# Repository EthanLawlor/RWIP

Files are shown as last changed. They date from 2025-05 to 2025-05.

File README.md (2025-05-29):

# 🛰️ Reaction Wheel Inverted Pendulum

This repository contains all hardware and software resources for the **Reaction Wheel Inverted Pendulum** project — a physical model of a CubeSat's attitude correction and control system. Developed as part of a Bachelor of Engineering (Honours) in Mechatronics at TU Dublin, the system demonstrates closed-loop stabilization using reaction wheels, an IMU, and PID-based control.

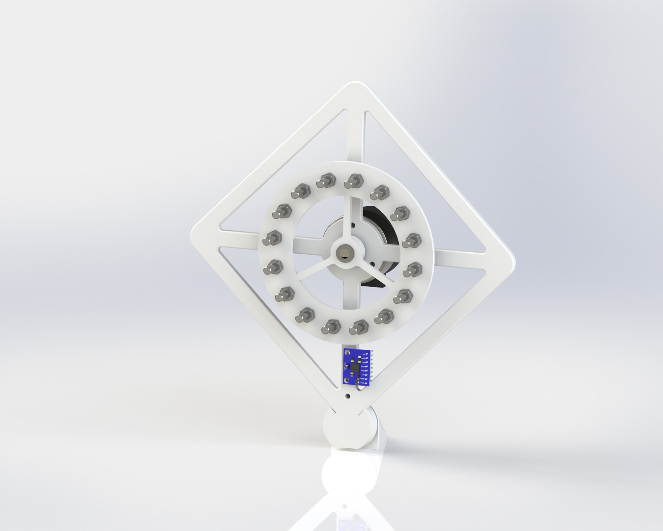
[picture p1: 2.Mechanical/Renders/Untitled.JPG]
3D Render of RWIP
  
*Figure: 3D render of the Reaction Wheel Inverted Pendulum prototype*

---

## 📦 Repository Structure

0. **Documentation**  
   - `RWIP-ProjectReport.pdf` – Full project report with modelling, design, and results

1. **Electrical**  
   - `KiCAD-PCB/` – Custom PCB for ATmega328P-based MCU, IMU, and power electronics  
   - Includes schematics, PCB layout, and Gerber files

2. **Mechanical**  
   - `SolidWorks-Assembly/` – Full CAD model of the pendulum frame and flywheel  
   - `STL-Files/` – 3D-printable parts for prototyping the mechanical structure

3. **Software**  
   - `Firmware/` – Microcontroller code for ATmega328P (Arduino-compatible)  
   - Implements sensor fusion (complementary & Kalman filters), cascade PID control, and encoder-based velocity feedback

---

## 🧠 Project Overview

This project simulates and physically demonstrates a 1U CubeSat’s ability to stabilize itself using internal momentum exchange via a reaction wheel. The system uses:

- **IMU**: MPU6050 (accelerometer + gyroscope)
- **Motor**: Nidec 24H brushless DC motor with encoder
- **MCU**: ATmega328P (Arduino Uno or custom PCB)
- **Control System**: Cascaded PID controller with feedback from IMU and encoder

---

## 🔬 Key Features

- Real-time stabilization of a pendulum system using reaction wheels
- Sensor fusion for clean angular state estimation (Kalman & complementary filters)
- Encoder RPM feedback and motor driver interface
- Fully 3D-printed mechanical structure with adjustable flywheel inertia
- Simulation-backed control strategy using Lagrangian modelling and Simulink validation

---

## 🛠️ Hardware Requirements

- ATmega328P MCU (Arduino Uno or custom PCB)
- MPU6050 IMU
- Nidec 24H brushless motor with integrated encoder
- 12V power supply and 5V linear regulator (LM7805)
- Reaction wheel (3D printed) with modular mass placement
- Supporting frame, bearings, and wiring

---

## 🧩 Software Features

- **Sensor integration**: I²C communication with MPU6050
- **State estimation**: Complementary and Kalman filtering
- **Control logic**: Cascaded PID loop with independent tuning
- **Motor interface**: PWM, direction, and brake pin management
- **Encoder**: Speed and direction estimation via interrupts
- **Serial monitoring**: Real-time feedback and tuning via PC interface

---

## 📚 Documentation

📄 The full design process, test results, simulations, and implementation details are documented in the [Project Report (PDF)](./0.Documentation/RWIP-ProjectReport.pdf).

---

## 🚀 Getting Started

### Setup Steps

1. **Assemble mechanical parts** using STL files or the full SolidWorks model
2. **Build the PCB** or use an Arduino Uno with the schematic provided
3. **Upload firmware** from `/Firmware` using Arduino IDE
4. **Power the system** with regulated 12V/5V supply
5. **View system behavior** and tune via Serial Plotter or Monitor

---

## 🔧 Control Strategy

- Inner loop: motor velocity PID control based on encoder feedback
- Outer loop: angle stabilization PID using fused IMU angle
- Designed and tuned iteratively based on test results and Simulink simulations

---

## 🧪 Future Work

- Expand to 3-axis stabilization using multiple wheels
- Switch to space-ready components for orbital deployment
- Integrate solar power system with MPPT for autonomous CubeSat operation
- Implement advanced control (LQR, SMC, nonlinear backstepping)

---

## 📝 License

This project is open-source and distributed under the terms of the [GNU General Public License v3.0 (GPL-3.0)](./LICENSE).

---

## 👤 Author

**Ethan Lawlor**  
B.Eng. Mechatronics  
Technological University Dublin

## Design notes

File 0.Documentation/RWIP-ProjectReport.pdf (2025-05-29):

TU DUBLIN BLANCHARDSTOWN

SCHOOL OF INFORMATICS AND ENGINEERING

# DEVELOPMENT OF AN OPTIMIZED ATTITUDE CORRECTION & CONTROL SYSTEM FOR A 1U CUBESAT

by

## Ethan Lawlor

## A report submitted in partial fulfilment of the

## requirements for the degree

### BACHELOR OF ENGINEERING (HONOURS) IN MECHATRONICS

### SUPERVISOR: SUBMISSION DATE:

ETHAN LAWLOR | BACHELOR OF ENGINEERING (HONOURS) IN MECHATRONICS | 30/04/2025
- ii -

### ABSTRACT

This report presents the end-to-end development of a reaction-wheel attitude-

determination-and-control system for a one-unit CubeSat. The work addresses the dual

challenge faced by small spacecraft, rapid detumbling after deployment and precise

pointing during routine operations, using only low-cost, commercial-off-the-shelf

hardware and firmware written from first principles .

A dynamic model of the inverted-pendulum system is derived with Lagrangian mechanics

and verified in simulation to guide controller design . Real-time attitude estimates fuse

accelerometer and gyroscope data first with a complementary filter and later with a Kalman

filter to reduce noise and drift while remaining computationally light . Stability is achieved

with a cascaded PID architecture in which an inner wheel-velocity loop feeds an outer

attitude loop, a structure selected for its ability to balance fast actuator dynamics against

slower body motions .

The report documents the electrical and mechanical builds, software flow charts, and

laboratory test methodology, detailing how iterative tuning, on-board data logging, sensor

filtering and a watchdog routine were used to refine performance and prevent controller

saturation . All design drawings and software codes are contained in the appendices to

lower the entry barrier for future attitude correction projects.

- iii -

### ACKNOWLEDGEMENTS

I would like to thank my lecturer, Niall Bell, for his guidance and support throughout this

project. His expertise and feedback were invaluable in shaping my work.

I also appreciate the encouragement and support from my friends and family, whose belief

in me kept me motivated during challenging moments.

Lastly, thank you to everyone who contributed to my education. Your help made this

journey possible.

- iv -

### DECLARATION

The work submitted in this report is the results of the candidate’s own investigations and

has not been submitted for any other award. Where use has been made of the work of other

people it has been fully acknowledged and referenced.

Ethan Lawlor

- v -

### TABLE OF CONTENTS

- vi -

- vii -

- viii -

### LIST OF ABBREVIATIONS

1 U One-Unit CubeSat standard (10 × 10 × 10 cm)

ADCS Attitude Determination and Control System

ADS Attitude Determination System

COTS Commercial Off-The-Shelf

DC | Direct Current (brushless DC motor)
DOF | Degrees Of Freedom (e.g., 6-DOF sensor)
EEPROM | Electrically Erasable Programmable Read-Only Memory
EPS | Electrical Power System
GNC | Guidance, Navigation and Control
GPS | Global Positioning System
GUI | Graphical User Interface
IMU | Inertial Measurement Unit
I²C / I2C | Inter-Integrated Circuit serial bus
ISS | International Space Station
LQR | Linear-Quadratic Regulator

MCU Microcontroller Unit (used for on-board processing)

MPPT Maximum Power Point Tracking (solar-array control)

PCB | Printed Circuit Board
PID | Proportional-Integral-Derivative (controller)
PPR | Pulses Per Revolution (encoder spec)

- ix -

PWM Pulse-Width Modulation

RPM | Revolutions Per Minute
RPS | Revolutions Per Second
RWS | Reaction Wheel System

RWIP Reaction Wheel Inverted Pendulum

SMC | Sliding Mode Control
USB | Universal Serial Bus

- x -

### LIST OF FIGURES

Figure 1. NanoRacks CubeSats being launched from the NanoRacks CubeSat Deployer on the ISS

- xi -

- xii -

### LIST OF TABLES

- 1 -

### Chapter 1 Introduction

This chapter presents a brief introduction to the need for attitude control in satellites, the

relevant background information and the scope of this project’s design solution.

Figure 1. NanoRacks CubeSats being launched from the NanoRacks CubeSat Deployer on

the ISS on February 25, 2014 (NASA Science Editorial Team, 2019).

### 1.1 An Introduction to CubeSats

A CubeSat is a class of small satellite designed to be deployed into orbit as secondary

payloads on a launch vehicle, or from the International Space Station, as seen in figure 1.

CubeSats are designed with a standardized size of 10x10x10 cm, also known as a “1U”

unit, to simplify their integration into deployment vehicles, but are modular and can consist

of multiple units, as seen in figure 2, and are often manufactured with commercial off-the-

shelf (COTS) components.

First conceived in 1999 to be a platform for scientific research and developing new space

technologies (NASA, 2024), as of 2024 there are now 2396 CubeSats launched, including

16 interplanetary missions. Academia was responsible for most CubeSat launches initially,

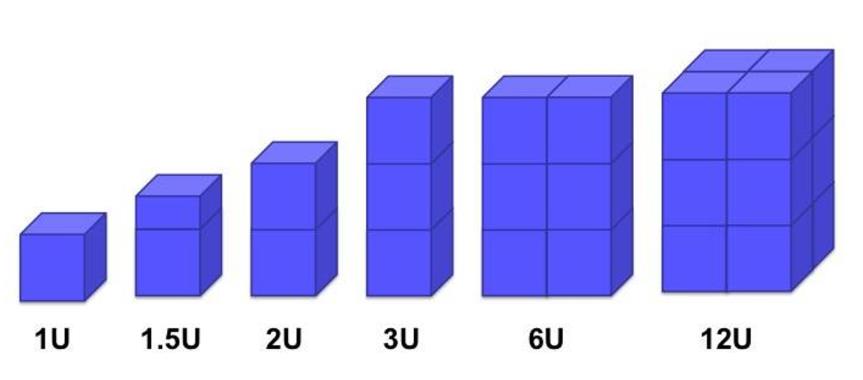
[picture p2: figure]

- 2 -

but by 2014 the majority of newly deployed CubeSats were for commercial or amateur

projects (Kulu, 2024).

Figure 2. A Sample of CubeSat Arrangements (NASA Science Editorial Team, 2019).

Most CubeSats deployed today are used for Earth observation, communications, and

scientific research, including climate monitoring, remote sensing, and technology testing.

Additionally, they are increasingly employed for commercial purposes, such as providing

data for telecommunication and internet services.

The expediated rate of growth in the nanosatellite commercial sector invites the need for

continuous development of increasingly simplified and COTS platforms for integration

into CubeSats.

### 1.2 Problem

Like larger satellites, CubeSats often feature multiple subsystems handling different tasks

in parallel including the flight computer, electrical power system (EPS), payload operation,

and primary control systems. A satellite’s Guidance, Navigation and Control (GNC)

subsystem encompasses the components used for position determination and the

components used by the Attitude Determination and Control Systems (ADCS) and is

crucial for a successful mission (NASA, 2024). Components used for ADCS include

- 3 -

reaction wheels, magnetorquers, thrusters, star trackers, sun sensors, Earth sensors, angular

rate sensors, and GPS receivers and antennas.

Due to asymmetric deployment forces and bumping with other CubeSats, tumbling

typically occurs during deployment. Some CubeSats operate normally while in a spin, but

others that require precise heading must be detumbled. Reaction wheels are commonly

used for their ability to impart relatively large amounts of moments on the overall system.

Once detumbled a CubeSats orientation may still needed to be controlled to align its

sensors for data acquisition or to optimize solar gain through its solar panel array. These

operations present the need to develop a control system for precise attitude control in three

axes for CubeSats, that doesn’t rely on exerting a force on an object external to the satellite.

### 1.3 Background

Figure 3. A Reaction Wheel being used to Control Orientation in one Axis (Dominik

Zaborniak, 2024).

The use of reaction wheels to control the orientation of a system is well-documented in

projects addressing the inverted pendulum problem, as illustrated in Figure 3 (Dominik

Zaborniak, 2024). In this case, the torque generated by the reaction wheel is sufficient to

counteract external disturbances and adjust the angular momentum of the system, including

the combined effects of the system's moment of inertia, existing angular momentums and

external disturbances. The reaction wheel imparts torque to the system, which is critical

for maintaining stability in an otherwise unstable configuration. An optimized control

- 4 -

system would regulate the torque applied by the reaction wheel based on the magnitude

and direction of the system's overall angular momentum, effectively stabilizing the system

and keeping it in an upright position.

To control the orientation of the CubeSat in three axes, three reaction wheels can be

arranged along its orthogonal axis, as in figure 4. This arrangement aligns each wheel to

impart a moment on the system around a primary axis of rotation, either the x-, y-, or z-

axis.

Figure 4. Three Axis Inverted Pendulum forming a cube (Bobrow, et al., 2020).

The Cubli, developed by Mohanarajah Gajamohan & colleagues in 2012, is an excellent

example of this three-axis configuration. In Cubli, the system dynamics are modelled using

Kane’s equations, and orientation of the system is described using Euler angles, and brakes

are incorporated to generate large torques from collisions with the wheel. These exert such

a large force on the system that Cubli can “jump” from a face to an edge, then from

balancing on the edge can jump again up onto a vertex, “catching” itself there and

maintaining balance (Mohanarajah, et al., 2012).

Other iterations of Cubli use various means of describing the angular displacement and

modelling the system dynamics. Papers by Fabio Bobrow and colleagues documents the

- 5 -

use of complex numbers to describe the angular displacement of a single cube face in 2D

(Bobrow, et al., 2020), and, by extension, unit ultra-complex numbers (quaternions) to

describe the angular displacement of the cube in 3D (Bobrow, et al., 2020). Using

quaternions avoids encountering singularities found in Euler angle mechanics, singularities

occur when the algorithm cannot find a solution to the required movements. The

Lagrange’s equations are used in these papers to derive a set of equations that describe the

motion of the system.

Once an equation of motion is determined, a control strategy is necessary to reduce and

eliminate the angle of displacement in the three dimensions and maintain stable orientation.

An example of a control algorithm reducing the angular velocity of a system in 3

dimensions to zero, i.e. trying to keep it still, is shown in figure 5. Proportional-Integral-

Derivative (PID) control is one of the most used methods for correcting orientation errors.

It adjusts the control input based on the current error, accumulated past error, and the rate

of change of the error. This method is effective for systems with relatively linear dynamics

and ensures precise orientation adjustments.

Another useful strategy is the Linear Quadratic Regulator (LQR), which minimizes a cost

function that penalizes both deviations from the desired state and the control effort. This is

particularly suitable when the system can be linearized around an equilibrium point,

providing optimal control for CubeSat attitude control around a point, while minimizing

both the angle state error and revolutions per minute (RPM) of the reaction wheel, keeping

the wheel speed to a minimum (Mohanarajah, et al., 2013).

- 6 -

Figure 5. An Example of PID control settling the angular velocity of a system

(Mohanarajah, et al., 2013)

These control strategies, when implemented appropriately, ensure that CubeSats maintain

precise orientation and stability in space.

### 1.4 Scope and Objectives

The scope of this project focuses on the design and development of an optimized attitude

correction and control system for a 1U CubeSat. The primary objective is to create a model

capable of stabilizing and orienting itself using reaction wheels as the primary actuators.

The model will simulate a CubeSat's behaviour, maintaining its orientation against external

factors such as gravitational forces, sensor noise, and the varying centre of mass and thus

the varying of moments of inertia configurations, not unlike when a CubeSat would deploy

a solar array. The project aims to ensure that the CubeSat remains stable, and can be

orientated about its yaw axis, enabling precise heading for data collection, optimal solar

panel alignment, and communication tasks.

Key technical objectives include conducting an in-depth literature review to investigate

current CubeSat attitude control technologies, reviewing flywheel system dynamics, and

analysing existing studies on control design for orientation. The project will then move on

- 7 -

to the design phase, including both mechanical and electronic components, with detailed

engineering drawings and circuit schematics. A comprehensive software flow diagram

outlining the control algorithms will also be developed.

Following the design, the project will simulate the proposed system using relevant software

tools to validate its functionality. Once validated, a prototype will be built, first for one

dimension then moving onto three dimensions, to verify the measurements and movements

of the attitude control system. The prototypes will be rigorously tested, and iterative

adjustments will be made to optimize the control algorithms based on performance

feedback. The final phase will involve comprehensive testing and evaluation to ensure the

CubeSat's attitude control system can stabilize the satellite and orient it to the desired

direction autonomously.

In addition to the core objectives, the project will explore the integration of a solar array

with Maximum Power Point Tracking (MPPT) to simulate varying configurations of mass

of the satellite. A graphical user interface (GUI) to display heading, pitch, roll, and a live

camera feed is also considered as a potential bonus feature to simulate data capture.

By the end of this project, a robust, low-cost, and efficient attitude control system for

CubeSats will be developed, with applications extending to public, private and commercial

sectors.

### 1.5 Document Overview

This document outlines the design, modelling, and testing of an optimized attitude

correction and control system for a 1U CubeSat. Chapter 1 introduces the key challenges

CubeSats face, particularly the need for precise attitude control to maintain proper

alignment of solar panels, sensors, and communication systems. The background section

discusses the use of reaction wheels for orientation control and explores various control

strategies that are employed to stabilize the CubeSat’s attitude in three dimensions.

Chapter 2 provides a comprehensive technical foundation for the CubeSat system. It begins

with the physical components of the CubeSat prototype, including the microcontroller,

- 8 -

motors, and reaction wheels. The chapter continues with a discussion on the derivation of

the equations of motion, which describe the CubeSat's dynamics and form the basis for the

attitude control system along with the PID error control. The different methods for

representing attitude, such as quaternions and Euler angles, highlighting their respective

advantages and challenges in CubeSat applications, are also detailed. This section explains

how these components are integrated to achieve stable and efficient attitude control.

In Chapter 3, the methodology for the construction of the CubeSat model is outlined,

followed by the implementation of the control system. This chapter also describes the

testing process, including simulations and real-world validation of the CubeSat's

performance. Chapter 4 presents the results from these tests, evaluating the effectiveness

of the attitude control system in stabilizing the model’s orientation. Finally, Chapter 5

concludes the report by summarizing the findings and offering recommendations for

further improvements in CubeSat attitude control systems.

- 9 -

### Chapter 2 Literature Review

This chapter presents a review of the technologies and methodologies for attitude control

in CubeSats. CubeSats require efficient and reliable systems to ensure precise attitude

control in orbit. This review covers essential topics, including the construction of a system

with manipulative dynamics, mathematical frameworks for attitude representation, and

linear and nonlinear control strategies. The work presented here is crucial to the

development of the CubeSat attitude correction system.

### 2.1 Reaction Wheel-Based Systems for Attitude Control

A reaction wheel system (RWS) is a key component in small spacecraft such as CubeSats

for precise attitude control, using spinning wheels to generate torques that modify the

spacecraft's orientation. As the wheels spin, they generate angular momentum, which is

transferred to the spacecraft due to the conservation of momentum. The principle can be

described by Newton’s Second Law of Motion when applied to rotating bodies, every

action having an equal but opposite reaction. This system does not require external

thrusters or fuel reservoirs, making it well-suited for small spacecraft like CubeSats, where

minimizing mass and maximizing efficiency are essential.

The Cubli is a prominent example of a 3D inverted pendulum system that uses three

reaction wheels mounted on the cube’s faces to control its orientation. By applying

controlled torques from these wheels, the Cubli can balance on its edge or corner. This

design, although originally developed for a ground-based balancing robot, provides the

relevant framework for CubeSat design due to the similarities in mechanics and constraints

on mass, volume, and power.

The mechanical structure of such RWS’s consists of a lightweight yet rigid housing, with

brushless DC motors driving the reaction wheels. For CubeSat applications, a similar

design can be adapted as the Cubli balancing in +1g gravity on Earth, proves the system’s

ability to work for space-specific, 0g, requirements.

- 10 -

In a CubeSat reaction wheel system, the reaction wheels are typically mounted on three

orthogonal axes. This setup provides full control over the spacecraft's attitude, allowing for

rotations around all three axes (yaw, pitch, and roll). The reaction wheels are controlled by

a feedback system that adjusts the wheel speeds based on input from sensors that measure

the spacecraft's orientation.

### 2.1.1 Mechanical Build of a Reaction Wheel Inverted Pendulum

For the development of a CubeSat model with a reaction wheel attitude control system, the

mechanical build would include:

1. Three Reaction Wheels: Each mounted on a face of the CubeSat. These wheels

will be coupled with motors to generate the required torques for attitude control.

2. Brushless DC Motors: These motors are ideal for CubeSats due to their efficiency,

precise control, and low power consumption. The motors must be mounted in such

a way that the CubeSat's centre of mass is close to the axis of rotation to minimize

the need for large control torques.

3. Structural Housing: The CubeSat housing must be designed to be lightweight and

durable, with a rigid framework that can withstand the forces generated by the

reaction wheels.

4. Sensors: IMUs (Inertial Measurement Units) are typically used for real-time

measurement of the CubeSat’s orientation. These units often combine

accelerometers, gyroscopes, and sometimes magnetometers to provide precise

attitude determination.

5. Microcontroller: A microcontroller unit (MCU) will be used to read the sensor

input and then output to the motor drivers accordingly based on the devised control

system. A development board with native Bluetooth and Wi-Fi connectivity will be

considered.

- 11 -
6. Electrical Power System: The electrical power system (EPS) will consist of a

battery bank with large enough capacity to support the three motors and other

electronics, a charge regulator for the battery and two voltage regulators, one for

the motors and one for the MCU and sensor

This mechanical setup allows for a compact and efficient attitude control system for

CubeSats, with minimal power consumption and no need for external propulsion systems.

The compact nature of CubeSats, however, imposes stringent limitations on mass and

power, requiring optimization of both the mechanical and electrical systems.

### 2.1.2 Reaction Wheel

The reaction wheel is a critical component in CubeSat attitude control systems, used to

generate torques that alter the spacecraft's orientation. The fundamental principle behind a

reaction wheel is the conservation of angular momentum: when the wheel spins, it creates

angular momentum, and any change in the wheel's angular velocity results in a

corresponding change in the CubeSat’s attitude. This key principle is essential for precisely

controlling the model’s orientation through the adjustment of the wheel’s speed and torque.

Figure 6. Inertia of an Annular Cylinder about Centre Axis (Moebs, et al., 2016)

The moment of inertia (I) of the reaction wheel is given by:

I =

m
2

(R1

2 + R2

2
) | (2.1)

- 12 -

Where m is the mass, and R1 and R2 are the inner and outer radii of the wheel. This

parameter determines the required torque to achieve specific angular accelerations

(Moebs, et al., 2016).

Key Parameters for Reaction Wheel Design:

### 1. Mass (m):

The mass of the reaction wheel affects its moment of inertia and torque generation.

A lighter wheel reduces the CubeSat's overall weight but may limit torque

generation, requiring a balance between sufficient torque and weight.

### 2. Radius (r):

The radius influences the moment of inertia. A larger radius increases torque

capability but also raises mass and power requirements.

### 3. Torque (τ):

The torque generated by the reaction wheel is related to angular acceleration by:

τ = I ⋅ α | (2.2)

Where α is angular acceleration. This equation governs how the reaction wheel’s

change in speed affects the model’s orientation (Beer & Johnston, 1989).

### 4. Angular Velocity (ω):

The angular velocity relates to angular momentum L, given by:

L = I ⋅ ω | (2.3)

Where ω is the angular velocity. This stored angular momentum is transferred to

the CubeSat, enabling attitude control (State Examinations Commission, 2011).

- 13 -

### 5. Kinetic Energy (Ek):

The kinetic energy in the reaction wheel is:

Ek =

1
2

### Iω²

(2.4)

This energy affects the CubeSat's power consumption and how efficiently it can

maintain orientation (State Examinations Commission, 2011).

### 6. Potential Energy (Ep):

The potential energy, especially in varying gravitational fields or when adjusting

orientation relative to a force, is given by:

Ep = mgℎ | (2.5)

Where h is the height or displacement relative to the gravitational source. This

energy must be accounted for in attitude adjustments (State Examinations

Commission, 2011).

### 7. Control Speed Limit:

The reaction wheel has physical limits, such as the maximum angular velocity and

the maximum torque it can generate. These limits must be factored into the control

system to avoid overdriving the wheel and ensure the CubeSat operates within its

capabilities.

### 8. Energy Efficiency:

Energy consumption is a key factor in CubeSat design. The reaction wheel's energy

use, including kinetic and potential energy, should be optimized to balance power

requirements for attitude adjustments within the CubeSat's limited power budget.

- 14 -

### 9. Rotational Inertia and Response Time:

The CubeSat's overall inertia determines how quickly it can change its orientation.

A higher CubeSat inertia requires more torque to achieve the same angular

acceleration, influencing the system's response time and stability (Mohanarajah, et

al., 2013).

By selecting appropriate values for these design parameters—such as mass, radius, moment

of inertia, torque, and angular velocity—the reaction wheel can be optimized for precise

CubeSat attitude control. These parameters are essential for ensuring the wheel can

generate the required torques while maintaining energy efficiency and operating within the

CubeSat's power constraints. Modelling these parameters accurately is key to integrating

the reaction wheel into the CubeSat’s attitude control system, ensuring stable and effective

orientation adjustments in space.

### 2.1.3 Motor

The reaction wheel system will use the Nidec24H brushless DC motor (model NCJ-24H-

12-01), which integrates the motor, motor driver, and encoder into a single unit. This

integrated design simplifies the CubeSat's attitude control system by reducing the number

of components and minimizing space, weight, and power consumption—critical

considerations for CubeSat applications. This model was chosen as it’s a readily available

COTS component.

- 15 -

Figure 7. Brushless DC Motor Nidec 24H (Nidec Corp., 2024)

Key Parameters for Motor Design:

### 1. Operating Voltage (V):

The motor operates at 12 V, which directly impacts the power consumption and

overall energy budget. This voltage level is chosen to balance power requirements

with the CubeSat’s limited energy supply.

### 2. Continuous Torque (τ):

The motor generates a continuous torque of 25 mN·m, which is essential for the

reaction wheel to produce the necessary forces for attitude control. This torque

value is a key parameter for determining the wheel's ability to alter the model’s

orientation.

### 3. Maximum Speed (ωmax):

The motor has a maximum speed of 2,500 RPM, which dictates how quickly the

CubeSat can adjust its orientation. The speed determines how fast the reaction

wheel can be spun to achieve desired attitude changes.

- 16 -

### 4. Encoder Resolution (PPR):

The motor includes an integrated dual line encoder with 200 pulses per revolution

(PPR), providing high-resolution feedback on the motor’s speed and position. This

allows feedback for precise control of the reaction wheel’s rotational velocity and

accurate feedback for attitude control.

### 5. Maximum Current (Imax):

The motor has a maximum current rating of 0.9 A, ensuring that it will not exceed

the model’s power supply capacity. This is important for managing the CubeSat’s

energy usage and ensuring that the motor operates within safe limits.

### 6. Efficiency and Design:

The brushless design of the motor ensures high efficiency, which is critical for long-

duration space missions where energy conservation is essential. The motor's design

also minimizes maintenance needs, as it has no brushes that could wear out over

time.

### 7. Control via PWM:

The motor speed is regulated by PWM (Pulse Width Modulation) control, which

adjusts the duty cycle of the signal sent to the motor driver. By varying the duty

cycle, the average voltage applied to the motor is controlled, which in turn controls

the speed and torque of the reaction wheel. This method efficiently regulates the

motor’s performance while minimizing power loss, allowing for fine control over

the reaction wheel’s speed.

These parameters are crucial for determining system power requirements and motor

behaviour, ensuring the reaction wheel system operates efficiently, while the integrated

encoder allows for precise feedback, enabling the model to maintain and accurately adjust

wheel speed (Nidec Corp., 2024).

- 17 -

### 2.1.4 Structure

The CubeSat structure is designed to support the reaction wheel and other critical components while

maintaining overall system integrity. It's built to house the motor, IMU, and other subsystems,

ensuring everything is secure and well-balanced.

Figure 8. Inertia for Slab About Centre Axis (Moebs, et al., 2016).

The main job of the structure is to provide a solid foundation for the reaction wheel and motor,

while also keeping the system’s centre of mass balanced. To get an accurate sense of the system's

dynamics in one dimension, the moment of inertia of the structure is calculated using a simple slab

model, as follows:

I =

m(a

2 + b

2
)
12

(2.6)

where m is the mass, and a and b are the dimensions of the model. This gives a starting point for

modelling the rotational behaviour of the CubeSat. As the CubeSat will be balancing on a vertex,

due to the limitations of gravity, the Parallel Axis Theorem is used to account for the offset of the

centre of rotation from the CubeSat’s centre of mass:

Ib = Ic + md

2
(2.7)

When dealing with three axis of rotation, the inertia tensor is a key parameter needed to model the

CubeSat's rotational dynamics. The inertia tensor, I, describes how the mass is distributed relative

to the CubeSat's three principal axes of rotation. For a simple CubeSat model, the inertia tensor can

be approximated using the parallel axis theorem, taking into account the mass distribution and the

geometry of the CubeSat. For a cube, the inertia tensor is diagonal and can be expressed as:

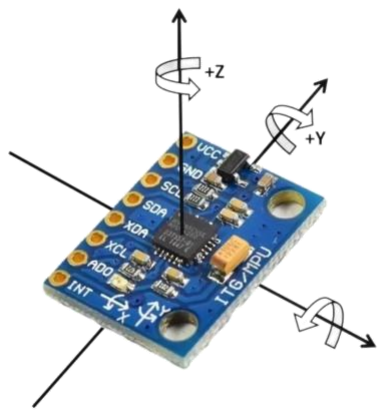
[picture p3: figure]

- 18 -

I =
[

1
6

mtotal(a

2 + b

2
) | 0 | 0

0

1
6
| mtotal(a

2 + b

2
) | 0
0 | 0

1
6
| | mtotal(a

2 + b

2
)
]

(2.8)

Where a, b, and c are the dimensions of the CubeSat, and mtotal is the total mass. The diagonal

elements represent the moments of inertia about the principal axes, while the off-diagonal elements

represent the products of inertia, which are assumed to be zero for a symmetric CubeSat with a

simple geometry (Beer & Johnston, 1989).

These parameters—total mass, centre of mass, and inertia tensor—are essential for deriving the

equations of motion for the CubeSat’s attitude control system. The equations of motion describe

the CubeSat's rotational dynamics under the influence of external torques (e.g., from the reaction

wheel) and disturbances (e.g., gravitational gradients, solar pressure). By accurately modelling

these parameters, the dynamics of the CubeSat can be simulated and controlled effectively using

the reaction wheel system.

### 2.1.5 Sensors

Figure 9. MPU6050 6 Axis Accelerometer/Gyroscope (Arrendondo, 2023)

The CubeSat model utilizes the MPU6050 sensor, an Inertial Measurement Unit (IMU)

that integrates both a 3-axis accelerometer and a 3-axis gyroscope. This sensor is essential

for determining the CubeSat's orientation and angular velocity in each axis, which are key

for the attitude control system. The MPU6050 provides real-time feedback on the

- 19 -

CubeSat's position and motion, enabling the precise measurements required to correctly

adjust the reaction wheel's torque in order to stabilize the model’s orientation.

The accelerometer measures linear acceleration along the X, Y, and Z axes, providing

information on the gravitational forces acting on the CubeSat. This data is used to

determine the CubeSat's tilt or attitude relative to the Earth’s surface. The gyroscope

measures the angular velocity along the same three axes, allowing the CubeSat's rotational

motion to be tracked and enabling the system to compensate for changes in orientation.

The MPU6050 communicates via I2C protocol, allowing for efficient data transmission

between the sensor and the CubeSat's microcontroller (ESP32). The sensor offers high

precision, with a range of ±2g to ±16g for the accelerometer and ±250 to ±2000 degrees

per second for the gyroscope, making it suitable for precise attitude measurement in small

spacecraft applications like CubeSats. (DFRobot, 2024)

This sensor is integral to the CubeSat’s attitude determination system (ADS), providing

the necessary data for the control algorithms to adjust the reaction wheel’s speed and thus,

its torque. By integrating the MPU6050 with the CubeSat's attitude control system, the

satellite can measure accurate orientation during its mission.

### 2.1.6 Microcontrollers

Microcontrollers serve as the central processing units in CubeSat systems, managing sensor data

processing, control algorithms, and communication tasks. The choice of microcontroller depends

on various factors such as processing power, memory capacity, power consumption, and interface

availability. Two commonly used microcontrollers are the Arduino Uno and the ESP32.

### 2.1.6.1 Arduino Uno

The Arduino Uno R3 development board, a widely used and easy-to-program microcontroller. It is

built around the ATmega328P 8-bit microcontroller, running at a clock speed of 16 MHz. Although

less powerful than other modern microcontrollers, it is capable of handling essential data processing

from the sensors and controlling the reaction wheel motor using PWM signals.

- 20 -

Figure 10. Arduino Uno Development Board

The Arduino Uno includes 14 digital input/output pins (of which 6 can provide PWM output), 6

analog inputs, and a USB connection for programming and serial communication. Its simplicity

and reliability make it a suitable choice for early-stage CubeSat designs and developmental

projects. The microcontroller offers 32KB of flash memory, 2KB of SRAM, and 1KB of EEPROM,

which are sufficient for basic control algorithms and sensor interfacing tasks.

The I2C interface on the Arduino Uno is used to communicate with the MPU6050 sensor, while

the GPIO pins are used to drive the motor interface, enabling precise control of the reaction wheel.

While the Arduino Uno consumes slightly more power relative to more advanced boards, it remains

an accessible and well-supported platform for prototyping CubeSat control systems (Arduino,

2025).

### 2.1.6.2 ESP32

The ESP32-DevKitC development board, a powerful and energy-efficient microcontroller.

It features a dual-core 32-bit processor running at up to 240 MHz, which is capable of

handling real-time sensor data processing from the MPU6050 and controlling the reaction

wheel motor via PWM signals.

- 21 -

Figure 11. ESP32 Development Board (DigiKey, 2024)

The ESP32-WROOM-DA chip used for this development board includes Wi-Fi and

Bluetooth connectivity, useful for testing and debugging, as well as communication with a

ground station during development. The microcontroller has 4MB of flash memory and

520KB of SRAM, providing enough resources to store control algorithms and handle data

processing tasks. (DigiKey, 2024)

The I2C interface on the ESP32 is used to communicate with the MPU6050 sensor, while

its GPIO pins interface with the motor driver, allowing precise control of the reaction

wheel. With low power consumption, the ESP32-WROOM is well-suited for CubeSat

applications, balancing performance and power efficiency within the CubeSat’s limited

resources.

### 2.1.7 Electrical Power System

The CubeSat's Electrical Power System (EPS) is designed to manage the power distribution

and charging of the batteries. The system was developed using KiCAD, a widely used

open-source electronic design automation (EDA) tool, to create a custom printed computer

board (PCB) that meets the specific power requirements of the CubeSat’s components.

- 22 -

Figure 12. Custom PCB for Electrical Power System

The PCB is designed to regulate power from the CubeSat's solar panels and distribute it to

critical components, including the microcontroller, sensors, and reaction wheel motor. The

system incorporates a charging circuit for the CubeSat’s battery, ensuring that the battery

remains charged during operation while preventing overcharging or deep discharge, which

could damage the battery. Voltage regulators on the custom PCB provide stable power to

different subsystems, such as the ESP32 microcontroller and the MPU6050 sensor,

ensuring that each component receives the appropriate voltage for safe operation.

The EPS also includes power monitoring capabilities, allowing the CubeSat to track battery

voltage and current draw to optimize energy usage and ensure that the system remains

within its power limits during the mission. By integrating all these power management

functions into a single custom PCB, the system minimizes size, weight, and complexity

while providing reliable power to the CubeSat’s attitude control system and other

subsystems.

- 23 -

### 2.2 Mathematical Methods for Attitude Representation

Precise modelling of spacecraft dynamics is a crucial aspect of attitude control. CubeSat

attitude determination relies on mathematical methods for representing rotations and

calculating the required torques to control the spacecraft's orientation. The following

mathematical methods are commonly used in spacecraft attitude determination and control:

### 2.2.1 Euler Angles

Euler angles provide a simple method for describing the orientation of a rigid body in three-

dimensional space. Using three rotational angles—yaw, pitch, and roll—Euler angles

define the orientation of the spacecraft relative to a reference coordinate system. The

rotations are typically performed about fixed axes, such as:

### R = Rz

### (φ)Ry

### (θ)Rx

(ψ) | (2.9)

where:

- φ is the yaw angle (rotation about the z-axis),
- θ is the pitch angle (rotation about the y-axis),
- ψ is the roll angle (rotation about the x-axis).

Although Euler angles are easy to understand and implement, they suffer from gimbal lock,

where two of the rotation axes become aligned, causing a loss of one degree of freedom.

This limitation makes Euler angles unsuitable for continuous and precise control over large

rotations.

### 2.2.2 Quaternions

Quaternions offer a more robust solution for representing rotations in three-dimensional

space. A quaternion consists of one scalar and three vector components:

q = q0 + q1i + q2j + q3k | (2.10)

- 24 -

where q0 is the scalar part and q1, q2, q3 are the vector components. Quaternions are

particularly advantageous in CubeSat systems because they do not suffer from singularities

and allow for smooth and continuous rotations.

The relationship between the quaternion and rotation matrix is given by:

R = [

1 − 2(q2

2 + q3

2
) 2(q1
q2 − q0

q3

) 2(q1
q3 + q0

q2

)
2(q1
q2 + q0

q3

) 1 − 2(q1

2 + q3

2
) 2(q2
q3 − q0

q1

)
2(q1
q3 − q0

q2

) 2(q2
q3 + q0

q1

) 1 − 2(q1

2 + q2

2
)

] (2.11)

This matrix can be used to transform vectors from the body frame to the inertial frame,

ensuring precise attitude control. (Kuipers, 1999)

### 2.2.3 Lagrangian Mechanics

Lagrangian mechanics provides a framework for modelling the dynamics of complex

systems, including spacecraft. The Lagrangian L is defined as the difference between the

kinetic energy T and potential energy U of the system:

L = T − U | (2.12)

The equations of motion are derived using the Euler-Lagrange equations, which describe

the dynamics of the system in terms of generalized coordinates (such as orientation angles)

and velocities:

d
dt (

dL

### dqi

̇

) −

dL

### dqi

= 0 | (2.13)

These equations allow the spacecraft's rotational behaviour to be predicted, providing the

necessary models for control system design (Goldstein, et al., 2002).

### 2.3 Sensor Integration for Attitude Determination

Inertial Measurement Units (IMUs) are essential for accurate attitude determination in

CubeSats, providing real-time data on orientation, angular velocity, and acceleration. A

typical IMU combines an accelerometer and a gyroscope to deliver comprehensive

- 25 -

orientation information. The MPU-6050 is a widely used IMU that integrates a 3-axis

accelerometer and a 3-axis gyroscope, offering reliable attitude data.

The accelerometer measures the force of gravity along each axis, enabling the

determination of tilt angles, while the gyroscope measures angular velocity, allowing for

the tracking of changes in orientation. To enhance the accuracy and reduce noise in attitude

estimates, these measurements are often fused using filters such as the Kalman filter or

Complementary filter.

### 2.3.1 Complementary Filter

θest(t) = α[θest(t − ∆t) + ωgyro ∙ ∆t] + (1 − α) ∙ θacc | (2.14)

The complementary filter is a computationally efficient method that combines

accelerometer and gyroscope data to estimate orientation. It blends the two sensors by

giving more weight to the gyroscope for short-term, high-frequency changes and more

weight to the accelerometer for long-term, low-frequency stability. This makes it effective

in many applications, especially when computational resources are limited, as it helps to

minimize the gyroscope's drift over time while maintaining accurate orientation (Halder,

et al., 2025).

### 2.3.2 Kalman Filter

### Anglekalman(k) = Anglekalman(k) + Gainkalman ∙ (Angle(k) − Anglekalman) (2.15)

The Kalman filter is an optimal estimation algorithm that combines sensor measurements

over time to produce more accurate estimates of a system's state. It works by continuously

updating the state estimate based on both the current sensor readings and the predicted

state, effectively minimizing the impact of noise. This makes it particularly effective in

systems with noisy data, and it is widely used in attitude estimation applications where

precise and reliable estimates are crucial (Candan & Soken, 2021).

- 26 -

By effectively integrating accelerometer and gyroscope data using these filtering

techniques, CubeSats can achieve precise and reliable attitude determination, which is

crucial for their navigation and control systems.

### 2.4 Control Algorithms for Attitude Stabilization

To achieve precise attitude control for CubeSats, several control algorithms are employed

depending on the system's complexity and the desired performance. These control methods

adjust the reaction wheel torque in real-time based on the CubeSat's orientation and angular

velocity, enabling the CubeSat to stabilize and eliminate any angular displacement.

### 2.4.1 Proportional-Integral-Derivative

Proportional-Integral-Derivative (PID) controllers are a widely used approach for

maintaining stability and reducing displacement, thanks to their simplicity and ease of

implementation. By tuning the proportional, integral, and derivative gains, a PID controller

can correct angular displacement and minimize oscillations effectively. This approach is

particularly useful in systems with relatively linear dynamics, where the model is

straightforward, and the system is responsive to simple feedback. The controller's output

adjusts based on three terms: the current error, the accumulation of past errors, and the rate

of change of the error.

The PID control law is:

### u(t) = Kpe(t) + Ki ∫ e(t)dt + Kd

### de(t)

dt

(2.16)

where:

- u(t) is the control input (torque),
- e(t) is the orientation error,

### - Kp, Ki

, Kd are the proportional, integral, and derivative gains, respectively.

- Proportional gain helps reduce large errors quickly.

- 27 -
- Integral gain eliminates steady state error.
- Derivative gain helps reduce overshoot and improve stability.

PID control is especially effective in applications like CubeSat attitude control, where

precise tracking of angular displacement is required over time (Beer & Johnston, 1989).

### 2.4.2 Cascade Loop

Figure 13. Cascade Loop Control Diagram (Dominik Zaborniak, 2024).

The cascade control loop is a commonly used strategy for controlling systems that require both fast

response and precise stabilization, such as the reaction wheel inverted pendulum (RWIP). In this

system, two nested feedback loops are implemented: an inner velocity loop and an outer position

loop. The inner loop controls the speed or torque of the reaction wheel based on feedback from the

motor’s encoder, allowing for quick adjustments and stabilization. The outer loop, on the other

hand, manages the pendulum’s angle by adjusting the desired motor speed according to the

pendulum's angular position and velocity, typically using a PID controller. This structure allows

the inner loop to handle fast dynamics while the outer loop focuses on maintaining the desired

orientation. By decoupling these two tasks, cascade control improves the overall performance and

stability of the system, making it ideal for applications like CubeSat attitude control where precise

orientation is essential (Dominik Zaborniak, 2024).

### 2.4.3 Linear-Quadratic Regulator

Linear-Quadratic Regulator (LQR) is another effective control strategy, particularly when

the system dynamics can be linearized around an equilibrium point. LQR aims to minimize

a cost function that penalizes both deviations from the desired state and excessive control

- 28 -

input. It is especially suitable for linear systems where a model of the system is available,

as it provides a systematic way to determine optimal control inputs.

The general LQR cost function is:

### J = ∫ (x(t) TQx(t) + u(t)

### TRu(t))dt

∞

0

(2.17)

Where:

- x(t) is the state vector (which includes the orientation and angular velocity),
- u(t) is the control input (reaction wheel torque),
- Q and R are positive definite weighting matrices that penalize state deviations and

control efforts, respectively.

The optimal control law is then given by:

u(t) = −Kx(t) | (2.18)

Where K is the gain matrix, which can be computed from the solution to the Riccati

equation. LQR controllers are particularly useful when precise, optimal control is needed,

such as in maintaining the CubeSat's orientation on its edge or corner (Mohanarajah, et al.,

2013).

### 2.4.4 Nonlinear Control

For systems where nonlinear dynamics cannot be ignored, nonlinear control strategies are

required. Nonlinear controllers account for the system's full dynamics, including the

interaction between reaction wheels and the CubeSat's rigid body. These controllers are

particularly useful when dealing with large angular displacements or when the system

operates outside of linear ranges.

Nonlinear control laws can be derived from the system's equations of motion using methods

such as Lyapunov’s direct method or by incorporating generalized momentum. These

- 29 -

methods are effective in stabilizing systems exhibiting significant nonlinearities, like the

Cubli, where the system must transition from a face to an edge or corner. The control law

typically takes the form:

u(t) = f(x(t), ẋ(t)) | (2.19)

Where:

- f(x(t), ẋ(t)) represents a nonlinear function based on the system's state and its

time derivatives (Mohanarajah, et al., 2013).

Nonlinear control is particularly useful for achieving stable, smooth transitions in attitude

control, especially when the CubeSat experiences large external disturbances.

### 2.4.4 Sliding Mode Control (SMC)

Sliding Mode Control (SMC) is a robust control technique that can handle system

uncertainties and external disturbances effectively. It works by forcing the system to "slide"

along a predefined surface, called the sliding surface, where the system's behaviour is

constrained to follow a desired trajectory. This is particularly useful for attitude control in

CubeSats, where external disturbances like gravitational forces or aerodynamic drag can

affect the satellite's orientation.

The sliding surface is typically defined as a function of the system's states:

σ(x(t)) = Cx(t) | (2.20)

Where CCC is a matrix that defines the sliding surface. The control law forces the system's

trajectory to reach and stay on this surface, which is designed to drive the system to a

desired equilibrium state. The SMC control law is then given by:

u(t) = −Ksgn (σ(x(t))) | (2.21)

Where:

- K is a constant gain,

- 30 -
- sgn(σ(x(t))) is the sign function, ensuring that the system stays on the sliding

surface (Liao, et al., 2020).

SMC is particularly advantageous in nonlinear systems with significant uncertainties or

disturbances, providing excellent robustness and stability.

### 2.4.5 Back-Stepping Control

Back-Stepping Control is a recursive control design method used to stabilize nonlinear

systems, especially those with multiple interacting states, such as CubeSats with reaction

wheels. It works by progressively designing controllers for different subsystems, starting

from simpler ones and working towards more complex parts of the system. At each step, a

Lyapunov function is constructed to ensure stability, and the control input is adjusted

accordingly.

The general approach involves choosing a candidate Lyapunov function for each

subsystem:

Vi

(xi

) =

1
2

xi

TPixi
(2.22)

Where Vi(xi) is the Lyapunov function for the i-th subsystem, and Pi
is a positive definite

matrix. The control law is then derived to ensure that the derivative of the total Lyapunov

function is negative, ensuring asymptotic stability.

This technique is particularly effective in systems like CubeSats, where the attitude control

involves multiple interacting components, such as the CubeSat body and the reaction

wheels (Mohanarajah, et al., 2012).

These control strategies are essential for stabilizing CubeSats, ensuring that they can

maintain precise orientation for sensor alignment, optimal solar panel positioning, and

other critical operations. The choice of control algorithm depends on the specific

application and the complexity of the system's dynamics.

- 31 -

### 2.5 Considerations for Space Deployment

The components used in this project—such as the Arduino Uno, MPU6050 IMU, and

Nidec brushless motor—are ideal for Earth-based prototyping due to their low cost and

ease of integration. However, these commercial off-the-shelf (COTS) parts are not suitable

for direct use in space, where conditions are far more demanding. Exposure to vacuum,

microgravity, and ionizing radiation can cause unshielded electronics to malfunction or fail

entirely.

For a space-deployable version of this system, components with space heritage and

radiation tolerance would be required. Microcontrollers, sensors, and power systems must

be tested for resistance to single-event upsets and thermal extremes. Materials must also

be selected for structural integrity under launch vibration and thermal cycling, replacing

3D-printed plastics with aerospace-grade metals or composites.

Finally, power management must be more robust. While the custom EPS works for lab

testing, space systems need radiation-hardened regulators, reliable battery protection, and

efficient solar energy capture. While the model is suitable for terrestrial-based attitude

control, transitioning this prototype to a real CubeSat would require significant upgrades

in electronics, thermal management, radiation shielding, and structural design.

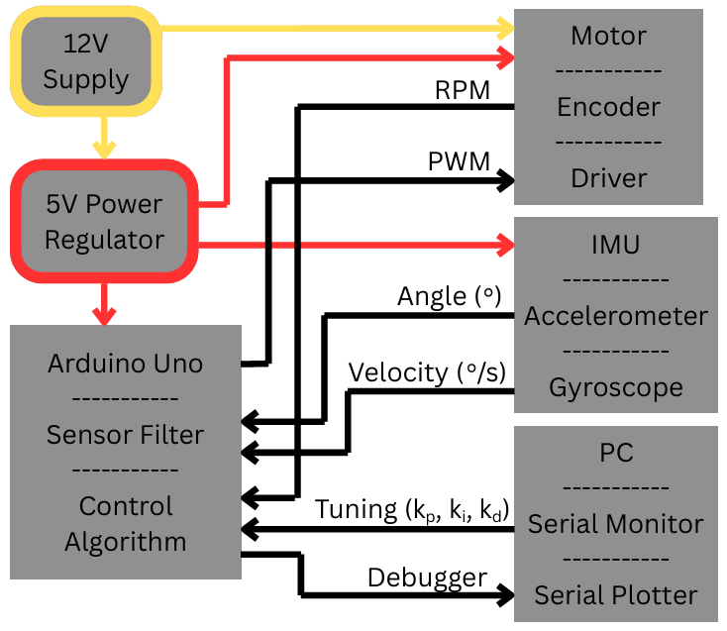
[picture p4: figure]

- 32 -

### Chapter 3 Materials and Methods

This chapter offers an in-depth explanation of the project's design and implementation

process. It outlines the various techniques and procedures employed to construct and

achieve the project's goals.

### 3.1 Project Block Diagram

The project block diagram, shown in Figure 14, illustrates the architecture of the reaction wheel

inverted pendulum system, which models an attitude correction and control system for CubeSats.

This diagram shows the interconnection between key components, outlining the flow of power,

data, and control signals throughout the system.

Figure 14. Project Block Diagram

- 33 -

At the top of the diagram, the 12V supply provides power to the motor through the driver. The

supply voltage is stepped down to 5V through a regulator, which then in turn supplies the IMU and

Arduino, and the motor’s driver and encoder. A common ground between all components is

necessary for correct communication.

The IMU communicates with the Arduino via the I2C (Inter-Integrated Circuit) interface on the A4

and A5 pins of the MCU. The I2C protocol allows one data line to communicate both the data from

accelerometer and the gyroscope to the microcontroller. This enables both the angular position, in

degrees, and angular velocity, in degrees per second, to be processed by a filter in the Arduino’s

sketch, firstly trying a Complementary filter, and then, depending on its performance, a Kalman

filter. The motor, when moving, will introduce a lot of noise to the sensor data through vibrations,

making accurate filtering vital for the project.

The Arduino Uno serves as the central control unit, processing sensor data and implementing the

PID control algorithm. The Arduino generates a PWM and a digital signal to control the motor

through the driver, adjusting the speed and direction of the Nidec 24H motor to adjust the torque

of the reaction wheel. The frequency of the PWM signal is configured to match the requirements

of the motor, best operating between 20-30kHz, ensuring efficient operation and precise control.

The encoder attached to the motor provides feedback on the wheel's RPM, which is sent to the

Arduino through digital pulses. The count of pulses is converted into RPM by dividing the count

by the PPR and the time. The encoder data, along with the IMU’s angular position and velocity

readings, allows the system to continuously fine-tune the motor's performance and maintain the

pendulum's balance.

Communication with the control system is facilitated via the Serial Monitor and Serial Plotter on a

connected PC, where the parameters can be tuned and their effect viewed in real-time. This

interface provides insights into control system performance and allows for the adjustment of control

parameters to ensure the optimal operation of the attitude correction system.

In summary, the block diagram demonstrates how the system components interact—providing

power to the motor, collecting sensor data, executing control algorithms, and adjusting motor

behaviour in real time to stabilize the pendulum. This architecture ensures efficient operation,

precise control, and the ability to fine-tune system performance during testing.

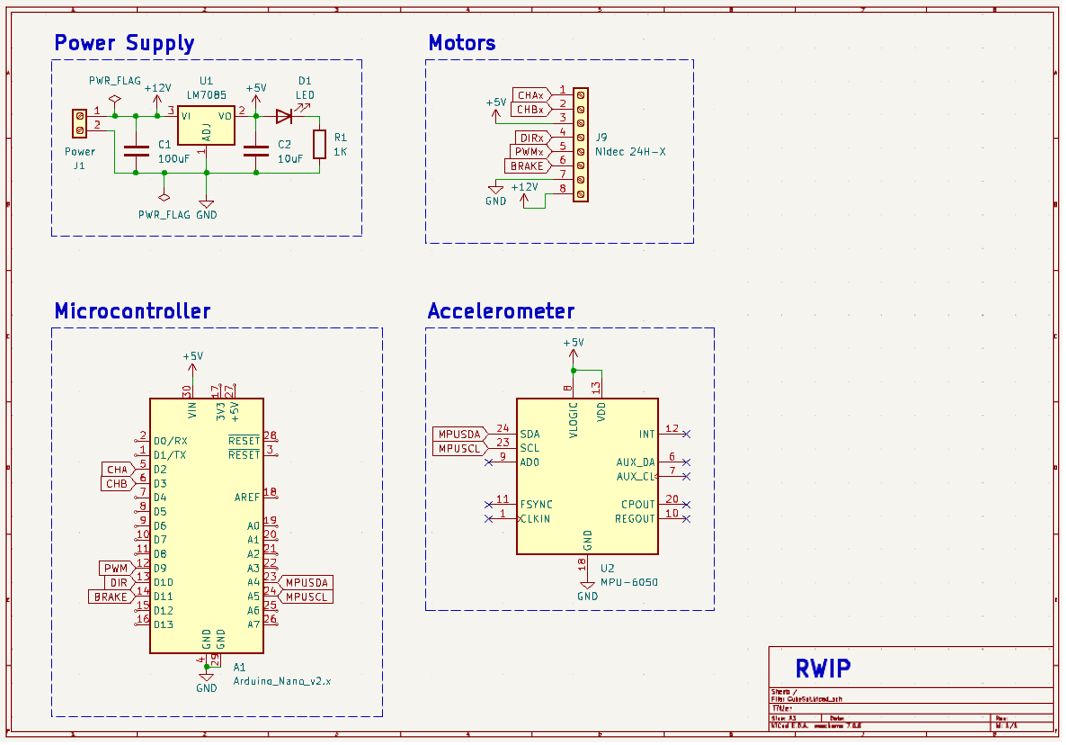
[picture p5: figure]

- 34 -

### 3.2 Electrical Build

The electrical design for the reaction wheel inverted pendulum focuses on detailing the power

distribution and communication.

Figure 15. Electrical Schematic.

The system is powered by a 12V supply, supplies the Nidec 24H brushless DC motor. The supply

is regulated through a LM7805 voltage regulator, stepping down the voltage to 5V to power the

Arduino Uno, the MPU6050 IMU, and the motors encoder. To ensure stable operation, capacitors

are placed on both the input and output sides of the LM7805: a 100µF capacitor on the input and a

10µF capacitor on the output, as recommended for optimal performance (Texas Instruments, 2016).

The Arduino Uno controls the motor through the PWM, Brake, and Direction lines, and it receives

digital pulses from the encoder on Channel A and Channel B lines, and orientation data from the

MPU6050 via the SDA and SCL pins, A4 and A5, which are connected to the respective data and

clock lines for I2C communication (DFRobot, 2024).

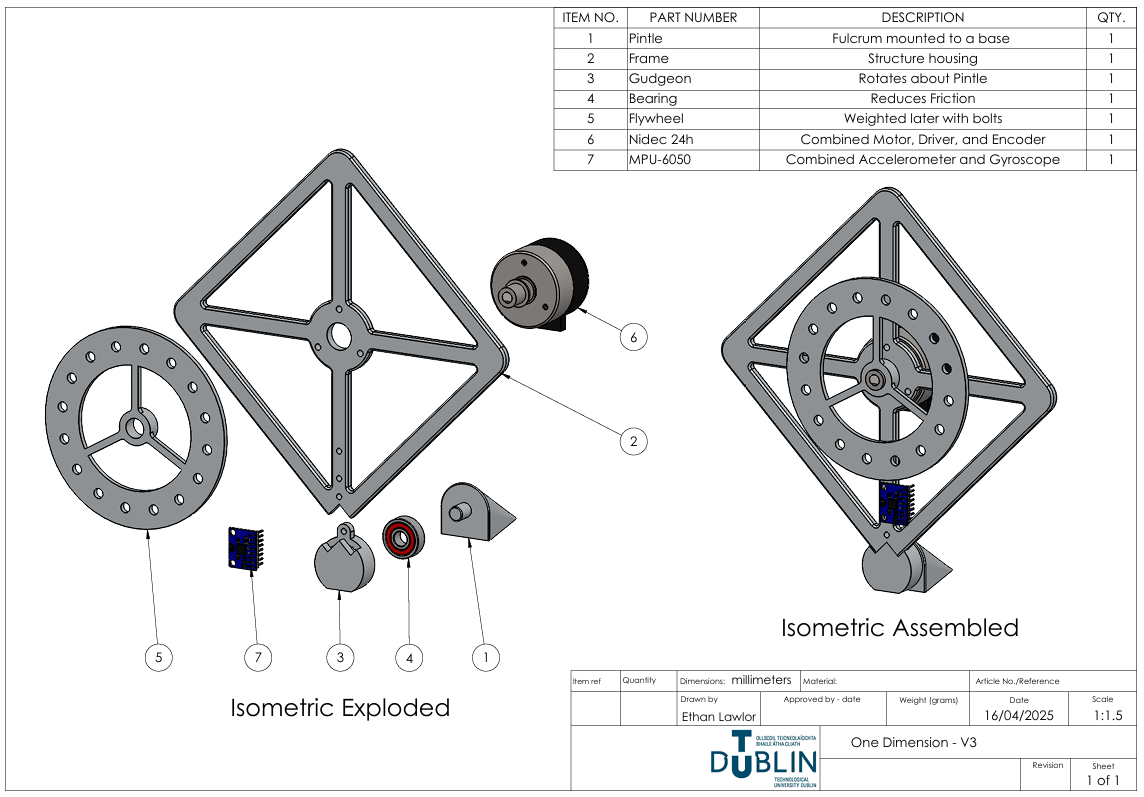
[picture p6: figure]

- 35 -

Communication and tuning of the system are facilitated using the Serial Monitor through the USB-

A port on the Arduino, where the control algorithm parameters are adjusted in real-time to fine-

tune motor control and attain optimal performance.

This electrical design ensures effective power distribution and stable operation, with the necessary

components to enable real-time control through the Arduino.

### 3.3 Mechanical Build

Figure 16. CAD Assembly Drawing.

The mechanical build consists of the flywheel, motor, IMU, frame, and pivot point. The Nidec24H,

MPU6050, and bearing being COTS components while the wheel, frame, gudgeon, and pintle are

designed using SolidWorks and 3D printed in PLA. Note the holes in the flywheel where bolts of

varying lengths can be added to increase or decrease the mass, and thus the inertial moment, of the

wheel.

- 36 -

Figure 17. Project Mechanical Build.

### 3.3.1 Design Considerations

The reaction wheel inverted pendulum was designed to simulate an attitude correction system for

CubeSats. Key design factors included weight distribution, wheel size, motor torque, IMU

placement, and system stability. The system is built to CubeSat size, specifically a 1U form factor

(10x10x10 cm), ensuring relevance for CubeSat applications.

A brushless DC motor, controlled via PWM signals, drives the reaction wheel, positioned near the

centre of mass to minimize torque requirements and improve efficiency. The wheel size was

selected to be the reasonably largest to better balance torque generation and power consumption,

with a 90mm diameter providing sufficient torque while staying within the power budget.

The IMU, an MPU6050, is placed close to the centre of rotation to minimize vibrations and ensure

accurate data. An Arduino Uno microcontroller processes this data and adjusts the motor speed in

real-time, maintaining balance and simulating CubeSat attitude control.

- 37 -

The structure is constructed using 3D-printed components to minimize mass, which is critical for

CubeSat applications. This compact design allows for easy adjustments during testing while

reflecting the constraints CubeSats face in terms of space and power.

### 3.4 Simulink Simulation

In this section the mechanical build is modelled mathematically using Euler-Lagrange and

simulated as a transfer function in Simulink. An appropriate control system can be modelled around

this equation to verify if the system is indeed controllable based on the mechanical builds specific

parameters, including weight, axis of rotation, and where the centre of mass is in relation to that

axis.

### 3.4.1 Deriving the Equations of Motion

To derive the equation of motion for the system the Euler-Lagrange Equation will be used. This

approach investigates the energy state transfer from kinetic to potential, describing it in forces in

an equation of motion.

### 3.4.1.1 Structure Inertia and Energy:

Figure 18. Parallel Axis Theorem Adjusts Inertia Based on Axis of Rotation.

Beginning with the structure, its inertia can be estimated as a uniform cuboid of side length l, where

the depth is irrelevant.

- 38 -

Moment of Inertia of a Slab:

I =

1
12 m(a

2 + b

2
) | (2.6)

IsG =

1
12 ms2l

2
(3.1)

Where a

2 = b

2 = l

2
for a cube.

IsG =

1
6

ms

l

2
(3.2)

Where IsG is the moment of inertia of the structure about its centre of mass, ms
is the mass of the

structure and l is the length of a side of the CubeSat’s one-dimensional model. The Parallel Axis

Theorem is now used to account for the difference in inertia from rotating about its centre to rotating

about a vertex, where d is that distance. That distance is related to the length of the side of the cube

through the basic trigonometry:

Sinθ =

A
H

(3.3)

Sin45° =

d
l

(3.4)

d =

l√2
2

(3.5)

Parallel Axis Theorem:

Ib = Ic + md²
(2.7)

IsO = IsG + ms (

l√2
2

)

2
(3.6)

IsO =

1
6

ms

l

2 + ms (

l√2
2

)

2
(3.7)

IsO =

1
6

ms

l

2 + ms (
2l

2
4
) | (3.8)

- 39 -

IsO =

2
12 ms

l

2 +

6
12 ms

l

2
(3.9)

IsO =

2
3

ms

l

2
(3.10)

Where IsO is the inertia of the structure about its vertex. Now that the inertia has been investigated,

the energy of this body in the system can be modelled.

Kinetic | Energy:

T =

1
2

Iω

2
| (2.4)

Ts =

1
2

IsOθ̇²
(3.11)

Where θ̇ is the angular velocity of the structure, ω = θ/dt, and IsO is the moment of inertia of the

structure about the axis of rotation.

Figure 19. Varying Potential Energy Based on Position.

Potential Energy:
U = mgℎ | (2.5)
Us = −msgdCosθ | (3.12)

- 40 -

Where ms
, is the mass of the structure excluding the wheel and motors rotor, d is the difference in

length from the centre of mass to the axis of rotation, g is the gravitational constant and θ is the

structures offset from the vertical plane in radians.

### 3.4.1.2 Wheel Inertia and Energy:

The same order of operations can be followed to determine an expression for the inertia, and thus

the energy of the wheel.

Moment of Inertia of Annular Cylinder:

I =

1
2

m(R1

2 + R2

2
) | (2.1)

IwG =

1
2
mwR | (3.13)

Where IwG is the moment of inertia of the wheel about its centre of mass, mw is the mass of the

wheel and R is the effective radius of the reaction wheels mass, i.e. R1

2 + R2

2

Parallel Axis Theorem:

Ib = Ic + md²
(2.7)

IwO = IwG + ms (

l√2
2

)

2
(3.14)

IwO =

1
2

mwR + mw (

l√2
2

)

2
(3.15)

IwO =

1
2

mwR + mw

2l

2
4

(3.15)

IwO =

1
2

mwR +

1
2

mwl

2
(3.16)

IwO =

1
2

mw(R + l

2
) | (3.17)

- 41 -

Where IwO is the moment of inertia of the wheel about the axis of rotation of the system, mw is

the mass of the reaction wheel including the motors rotor, R is the effective radius of the rings mass,

from Figure 6, and l is the length of the side of the cube.

Kinetic Energy:

T =

1
2

Iω

2
(2.4)

Tw =

1
2

IwOφ̇

2
(3.17)

Where φ̇ is the angular velocity of the wheel and IwO is its moment of inertia.

Potential Energy:
U = mgℎ | (2.5)
Uw = −mwgdCosθ | (3.18)

Where mw, is the mass of the wheel, d is the difference in length from the centre of mass to the

axis of rotation, g is the gravitational constant and θ is the structures offset from the vertical plane

in radians.

### 3.4.1.3 The Lagrangian:

The Lagrangian is the difference between the sum of kinetic and sum of potential energies in the

system and is the foundation of the Euler-Lagrange equation.

L = T − U | (3.19)
L = Ts + Tw − Us − Uw | (3.20)

L =

1
2

IsOθ̇² +

1
2

IwOφ̇

̇² − (−msgdCosθ) − (−mwgdCosθ) | (3.21)

L =

1
2

IsOθ̇² +

1
2

IwOφ̇

̇² + msgdCosθ + mwgdCosθ | (3.22)

L =

1
2

IsOθ̇² +

1
2

IwOφ̇

2 + (ms + mw)gdCosθ | (3.23)

- 42 -

Euler-Lagrange Equation:

d
dt (

dL
dθ̇

) −

dL
dθ = τreaction | (2.13)

Expression in brackets:

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
IsOθ̇² +

1
2

IwOφ̇

2 + (ms + mw)gdCosθ) | (3.24)

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
IsOθ̇²) | (3.25)

dL
dθ̇

= 2 (

1
2
IsOθ̇¹) | (3.26)

dL
dθ̇
= IsOθ̇ | (3.27)

First term of equation:

d
dt (

dL
dθ̇

) =

d
dt (IsOθ̇) | (3.28)

d
dt (

dL
dθ̇
) = IsOθ̈ | (3.29)

Second term of equation:

dL
dθ =

d
dθ (

1
2

IsOθ̇² +

1
2

IwOφ̇

2 + (ms + mw)gdCosθ) | (3.30)

dL
dθ =

d
dθ ((ms + mw)gdCosθ) | (3.31)

dL
dθ = −(ms + mw)gdSinθ | (3.32)

Resulting equation of motion for the system:

∴ IsOθ̈+ (ms + mw)gdSinθ = τreaction | (3.33)

- 43 -

IsO is the moment of inertia of the structure about the axis of rotation of the system, and is θ̈is the

angular acceleration of the structure, ms

is the mass of the structure, mw is the mass of the wheel

including the motors rotor, g is the gravitational constant, d is the distance from the centre of gravity

to the pivot point, θ is the structures offset angle from the vertical axis, and τreaction is the reaction

torque required by the wheel to align the structure vertically.

Thus, the reaction torque generated by the flywheel needs to overcome the torque of the structure

moving about the axis of rotation, and the potential energy of the two bodies in their current

position.

The resulting equation of motion can be simplified further by substituting IsO with its expressing

in terms of ms and l, from Equation 3.10, along with d being substituted for its expression in terms

of l, from Equation 3.5. Note that the resulting Equation 3.34 can be changed with Equation 3.33.

IsO =

2
3

ms

l

2
(3.10)

d =

l√2
2

(3.5)

Substituting into the result of the Euler-Lagrange equation:

IsOθ̈+ (ms + mw)gdSinθ = τreaction | (3.33)

2
3

ms

l

2θ̈+ (ms + mw)gl

√2
2
Sinθ = τreaction | (3.34)

The values are substituted for one’s measure from the mechanical build;

- mw – mass of the wheel = 0.036kg.
- ms – mass of the structure = 0.156kg.
- l − is the length of the side of the cube = 0.120m.
- θ − is the position of the structure from vertical in rad.
- θ̈− is the angular acceleration of the structure in rads⁻² , determined from taking a running sample from the IMU’s accelerometer where θ̈= θ̇/dt.
- g − is the gravitational constant, on Earth = 9.81 ms

−2

- 44 -

### 3.4.2 Obtaining the Transfer Function

To graph the function in Simulink, its transfer function needs to be obtained.

The equation being used for ease is:

IsOθ̈+ (ms + mw)gdSinθ = τreaction | (3.33)

For small-angle approximations, we can linearize the system by assuming that Sinθ ≈ θ, when θ

is a small value. This leads to the linearized equation:

IsOθ̈+ (ms + mw)gdθ = τreaction | (3.35)

Laplace Domain:

IsOs

2θ(s) + (ms + mw)gdθ(s) = τ(s) | (3.36)

θ(s)[IsOs

2 + (ms + mw)gd] = τ(s) | (3.37)

G(s) =

θ(s)
τ(s)

=

1
IsOs
2 + (ms + mw)gd | (3.38)

The denominator can be equated to Equation 3.33, and equally, Equation 3.34, leading to the

following expression:

G(s) =

1
2
3

ms

l

2s

2 + (ms + mw)gl √2
2

(3.39)

Substituting the known parameters and simplifying

G(s) =

1
2
3

(0.156)(0.120²)s

2 + (0.156 + 0.036)(9.81)(0.120)

√2
2

(3.40)

G(s) =

1
0.0015s
2 + 0.1598 | (3.41)

G(s) =

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
s + 1

(3.42)

- 45 -

Comparing this to the general form of a second order transfer function shown in Equation 3.42, the

need to divide each term on the right-hand side by 0.1598 in apparent to bring the constant in

denominator to 1:

G(s) =

6.267
0.009s

2 + 1

(3.43)

Plugging this function into a Simulink model give the following result:

Figure 20. Simulink Model of Equation 3.43.

Figure 21 shows that the system is inherently unstable without control. The system oscillates

indefinitely, never settling at the desired output of 1, this reveals the necessity of a control algorithm

to direct the output towards stability.

Figure 21. Step-Response to Transfer Function 1.

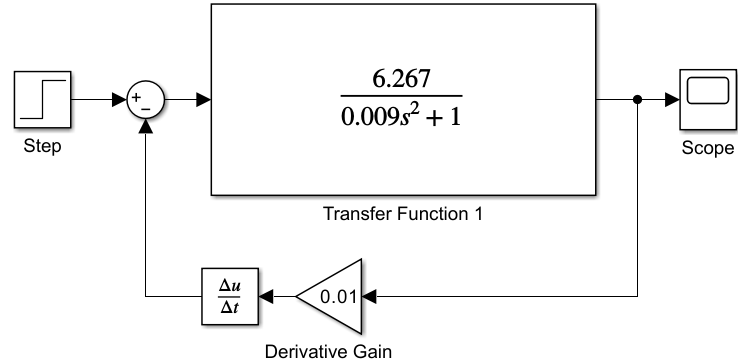
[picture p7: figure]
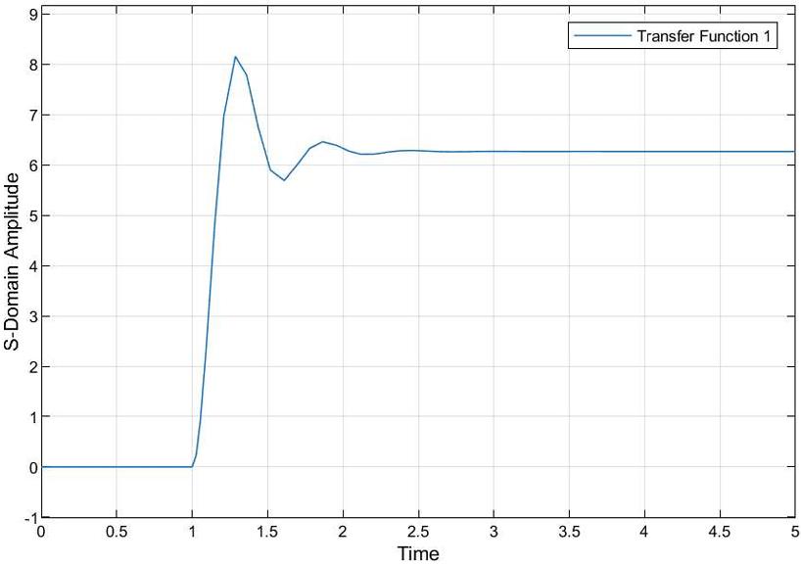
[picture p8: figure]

- 46 -

### 3.4.3 Adding Derivative Control

The first term implemented from PID control, from Equation 2.16, is derivative control. Derivative

control helps reduce overshoot and improves stability by predicting the future state of the system

from the previous error order:

Figure 22. Derivative Control of System.

Figure 23 shows that a derivative gain can produce an inaccurate yet stable output. The output

settles in a reasonable time but fails to approach the desired output. The need for more control is

evident.

Figure 23. Step-Response to Derivative Control

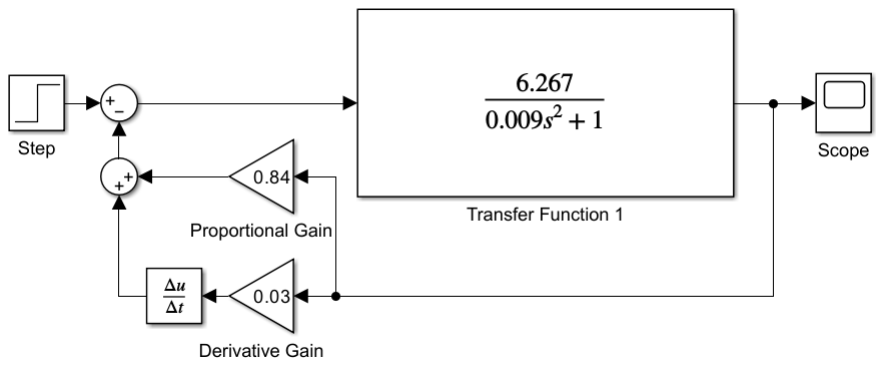
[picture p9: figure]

- 47 -

### 3.4.4 Adding Proportional Control

The P from PID control, from Equation 2.16, is proportional control. Proportional control helps

reduce reduces large errors quickly, by providing a control output that is directly proportional to

the size of the error:

Figure 24. Proportional-Derivative Control of System.

Figure 25 shows how the inclusion of proportional control has drastically diminished the initial

error, and thus the error of every timestep following it. The combination of proportional and

derivative gain has resulted in achieving the desired steady state output in a controlled and steady

manner.

Figure 25. Step-Response of Proportional-Derivative Control.

- 48 -

### 3.4.5 Simulation Results and Conclusions

The model proposed in Figure 25 yielded a satisfactory output, indicating that the inherently

instable system represented by the mechanical design, with its specific masses and moments of

inertia for the wheel and structure, can be controlled appropriately.

### 3.5 Software Design

With the mechanical design being verified through means of mathematical simulation, the software

implementation can begin. This section shows how to integrate the motor’s driver and encoder, and

the IMU’s accelerometer and gyroscope, with the microcontroller’s code, to be used in the control

algorithm.

### 3.5.1 Software Flow Charts

The flow charts in this section offer an overview of the flow of data and the decision-making

process of the software for this project.

### 3.5.1.1 Single Loop Control

The flow chart in Figure 26 shows how the Simulink block diagram, from Figure 24, can be

achieved with coding logic, a target value is set, a sensor gives input data allowing an error to be

determined, the PID control system applies its gains to the various error interpretations and a value

is calculated for the motor speed. This change in motor speed leads to a change in angle and

ultimately a change in error for the next iteration of the loop.

- 49 -

Figure 26. Single Loop PID Control.

### 3.5.1.2 Cascade Loop Control

The single loop has been verified to work in a simulated virtual environment but this does not

guarantee success so an alternative must be prepared. A dual PID controller, often called a cascade

loop, uses an inner loop to control the speed of the motor and an outer loop to control the angle of

the system.

- 50 -

Figure 27. Cascade Loop PID Control.

The inner loop adjusts the setpoint of the outer loop, this increases the responsiveness of the outer

loop and limits the output speed of the motor preventing its saturation, an effect where the wheel

is spinning so fast a large change in velocity can’t be induced to correct the output angle.

### 3.5.2 Motor Driver

The motor driver is inbuilt into the Nidec 24H motor, it is very simple in that it takes a binary

signal, High or Low, for the direction and brake and a PWM signal, 0-255, for the motor speed.

This specific motor works best when its pulse width modulated duty cycle is modulated at a

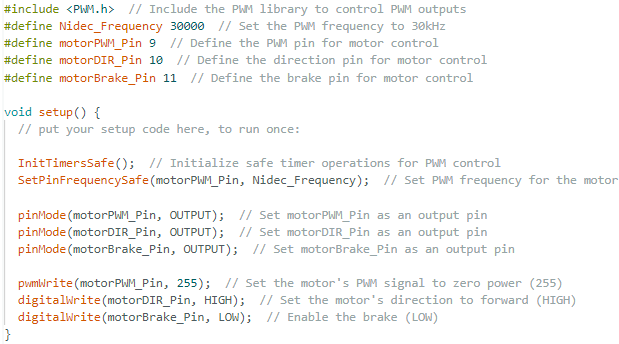
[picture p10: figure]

- 51 -

frequency of 20-30kHz. This is attained through use of a library to change the Arduino’s default

frequency for PWM signals of 480Hz to the desired rate.

Figure 28. Motor Driver Code.

Once the motor’s brake, direction and pwm pins are assigned and declared as outputs, control is

achieved from the following:

Table 1. Nidec24H Motor Pin Controls.

motorPWM_Pin | 0 | Max Speed | 255 | Min Speed
motorDir_Pin | LOW | Clockwise | HIGH | Counterclockwise
motorBrake_Pin | LOW | Brake Engaged | HIGH | Brake Disengaged

Note that the output of the control algorithm will have to be contained between 0 and 255 for the

motor speed. It will also have to be inverted where the largest output of the control algorithm maps

to 0 and the lowest output aligns with a 255 input for the motor to speed up and slowdown in the

correct direction. This is seen later in Figure 41.

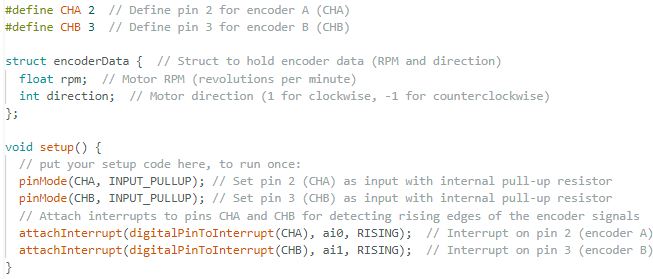
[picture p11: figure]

- 52 -

### 3.5.3 Encoder

The encoder is also inbuilt into the Nidec 24H motor, it has 2 lines which both send a signal and

need to be declared as inputs.

Figure 29. Encoder Set Up Code.

The device has two optical encoders, on two digital input lines, that are out of phase with each

other. These encoders are triggered one after the other in one direction, then, once the direction is

reversed, the initial signal that was lagging becomes the leading signal, allowing the code to

determine the direction as well as the angular velocity of the reaction wheel. This logic is exercised

in the two interrupt service routines, seen in Figure 30. The use of interrupts allows the processor

to effectively multi-task by pausing its main program execution to execute a service routine.

Figure 30. Encoder Interrupt Service Routines.

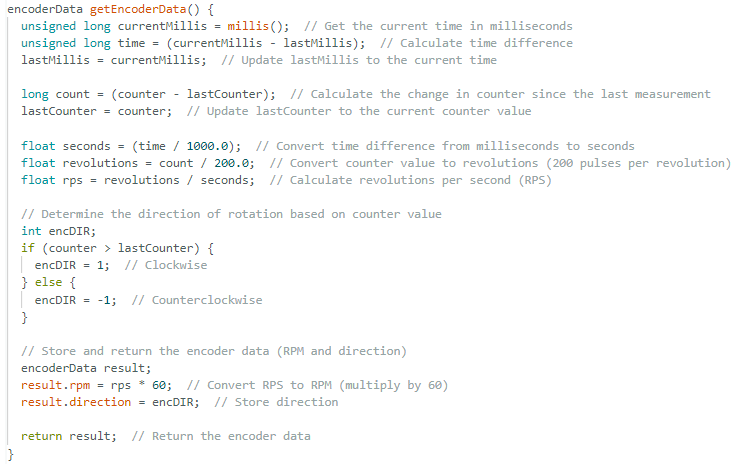
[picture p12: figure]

- 53 -

The counter value is passed to a custom function on each iteration of the main loop to determine

the speed and the direction, from its current value, previous value, and the time between function

calls, factoring in the pulses per revolution.

Figure 31. Encoder Speed and Direction Code.

The results are stored in a struct variable, a class of variable container that can be arranged to hold

multiple variable of different data types as seen in Figure 29. This allows the main loop to call this

function to update the values in a struct to be used in calculations or printed to the serial monitor.

Figure 32. Using the Encoder Custom Function.

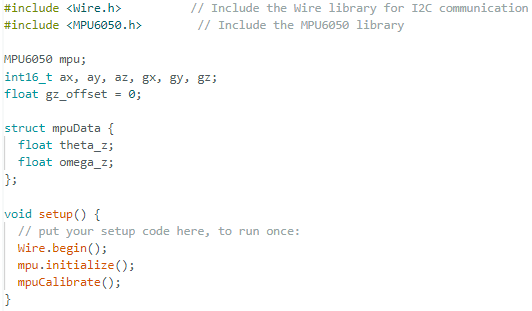
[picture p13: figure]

- 54 -

### 3.5.4 IMU

The microcontroller uses its I2C bus to communicate with the MPU6050’s accelerometer and

gyroscope. This is facilitated by a library that’s abstracts the use of addresses and bit registers,

simplifying the code. This is used in conjunction with a library for the specific MPU6050 IMU that

avoids involves bit masking and shifting of these addresses.

Figure 33. MPU6050 Set Up Code.

A sample of values need to be taken when the sensor is still to calibrate its reading. Several sensor

readings are taken and their average found. This average is then subtracted from each reading, when

still this results in output values closer to zero, which is ideal for a stationary sensor that reads

motion.

Figure 34. MPU6050 Calibration Code.

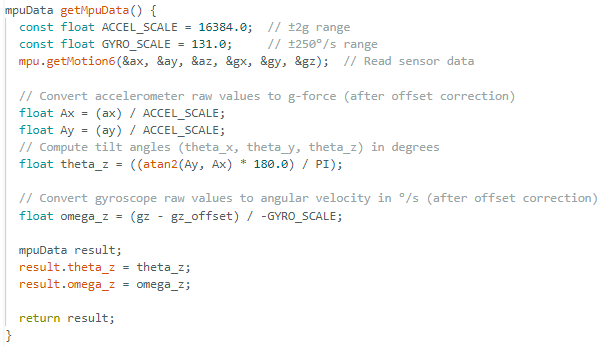
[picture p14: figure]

- 55 -

A custom function is then implemented to call on the IMU to update sensor reading values. These

values are scaled appropriately and used to calculate the angle and velocity of the system. The

accelerometer is ranged to the highest sensitivity option, ±2g, for the slow falling system, and since

its output is in radians, it is multiplied by 180/PI to convert it into degrees. To determine the

system's orientation, the code float tℎeta_z = atan2(Ay, Ax) is used to compute the angle

between the 2D vector formed by the Ax and Ay components, with respect to the positive x-axis,

once the correct quadrant has been considered. The gyroscope is also scaled to the highest

sensitivity range of ±250°/s while being orientated correctly, and then the previously calculated

value from the calibration function is subtracted to get a more accurate reading.

Figure 35. MPU6050 Angle and Angular Velocity Code.

These values for the angular position and velocity are then stored in a struct to be used by the main

loop. Again, the main loop creates a new ‘mpuData’ struct variable called ‘mpuData’, and calls

‘getMpuData()’ to fill the struct with the angle and velocity values, identical to the encoder data

exchange from custom function to main loop.

Figure 36. Using the MPU6050 Custom Function.

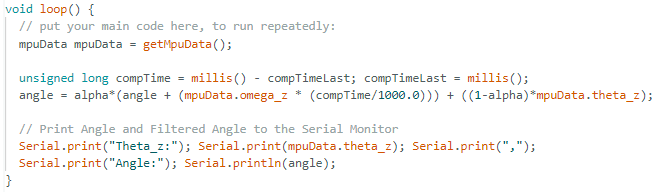
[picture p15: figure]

- 56 -

### 3.5.5 Complementary Filter

The complementary filter is executed in the main loop. It takes both the angle and the acceleration

and combines them in accordance with Equation 2.14. This combines a large amount from the

gyroscope reading and a small amount from the accelerometer reading to give an output angle that

is less susceptible to noise to and drift.

Figure 37. Complementary Filter Code.

### 3.5.6 Kalman Filter

The Kalman filter runs in the main loop. It takes the predicted angle and the measured angle,

blending them using the Kalman gain, which is calculated based on the uncertainty of both the

prediction and the measurement. The filter gives more weight to the gyroscope for quick changes,

while the accelerometer helps correct drift and noise. The uncertainty decreases as the filter trusts

the measurements more, leading to a more accurate and stable angle estimate over time. This

dynamic adjustment between the gyroscope and accelerometer ensures that the filter adapts to the

noise levels and provides reliable results.

Figure 38. Kalman Filter Custom Function.

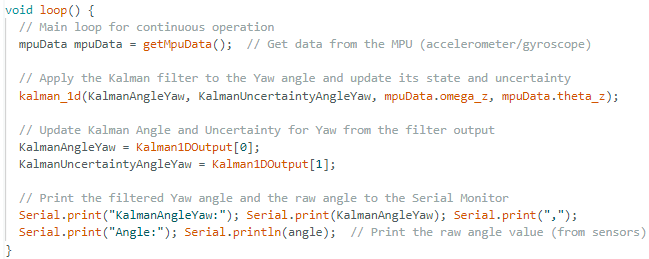
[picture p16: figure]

- 57 -

The main loop calls this function after communicating with the IMU to filter its data into an

accurate sensor reading free of noise, acceptable for use in situations where fine control is needed.

The logic of this function is based on one used by an open-source DIY drone created by Carbon

Aeronautics and is sufficient for flight controls, proving its effectiveness in turbulent environments

(CarbonAeronautics, 2022).

Figure 39. Using the Kalman Filter Custom Function

### 3.5.7 PID Control

The filtered angle is processed by a PID control algorithm to determine an output for the motor.

The error is defined as the difference between the filtered angle and the desired angle. Proportional,

integral, and derivative gains are applied to their various evaluations of the error, Equation 2.16.

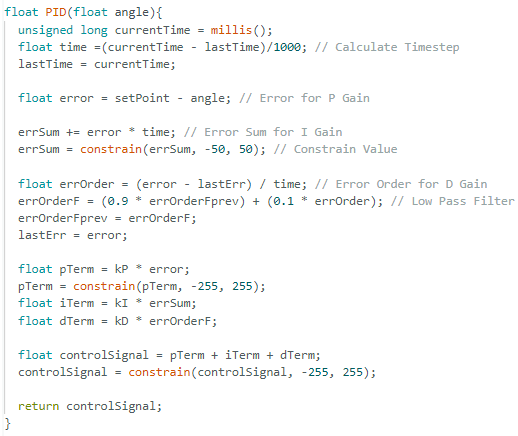
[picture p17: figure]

- 58 -

Figure 40. PID Control Code.

The proportional term has its gain applied directly to the error. This term is constrained to the max

motor output value, in either direction, this helps with responsiveness to the effect of other terms

whereby if the value was excessively large the other terms values would be negligible. The integral

term has it gain applied to the sum all previous errors. The error sum is also constrained to cap its

effect on the output. The derivative term applies its gain to the rate of change of the error over time,

or the error order. A low pass filter is applied to the error order, this allows the value to move

steadily without large deviations overly effecting the output.

Figure 41. Using the PID Custom Function.

- 59 -

The combination of the different terms given as a control signal to the motor. Angle deviation could

be positive or negative so the resulting value from the PID control could also be either. As the

motor only accepts positive integer values and moves at top speed when the input signal is 0, the

following conversions need to be done. Assume the output of the PID control is -255, requiring

max speed in the counterclockwise direction, considering Table 1 for Nidec 24H motor control:

- -255<0, therefore the motor direction is set to counterclockwise.
- The motor driver only accepts positive integers, the absolute value of -255 is 255.
- 255 is minimum speed but 255-255=0 gives the maximum speed.

This logic works with any value from -255 to +255:

- Control signal = +5. This is greater than zero, so direction is clockwise.
- The absolute value is +5.
- 255-5=250, resulting in a slow motor speed.

Both this code implementation of the PID control algorithm and the following tuning function and

cascade loop are highly inspired by Pavlo Bohdan, fellow Technological University Dublin alumni

(Bohdan, 2016).

### 3.5.8 Cascade Loop

In the cascade loop, two PID control functions are nested one within the other. The inner speed

control loop works off the RPM of the wheel to determine a setpoint for the outer orientation control

loop. The output from the encode has a low-pass filter to prevent large deviations or potential noise,

leading to a smoother input for the speed PID control loop.

- 60 -

Figure 42. Using a Cascaded PID Loop.

The error for the outer loop is the speed of the wheel, the larger the speed the bigger the error. This

alters the setpoint of the inner loop by a certain degree, increase the response and effectiveness of

the inner loop’s gains.

Figure 43. Errors for Inner and Outer Loops.

### 3.5.9 PID Tuning

The Arduino’s has non-volatile memory, memory that doesn’t erase after power down, called

Electrically Erasable Programmable Read-Only Memory, or EEPROM for short. It is not innately

capable of storing float variables, so a library is utilised to spread the value of the float over four

storage addresses, enabling it to be written to and read from the EEPROM.

- 61 -

Figure 44. Using PID Tuning Custom Function.

A character is sent from the serial monitor by the user, the main loop detects the available data and

calls the PID tuning function. The tuning function reads the available character and executes a

specific routine based on the characters corresponding switch case. The gains can be varied

individually or written to all at once to clear them, program parameters can be altered in this way

also to start or stop the motor or print values for debugging. A default case is executed if no match

is found for the command character

Figure 45. PID Tuning Code

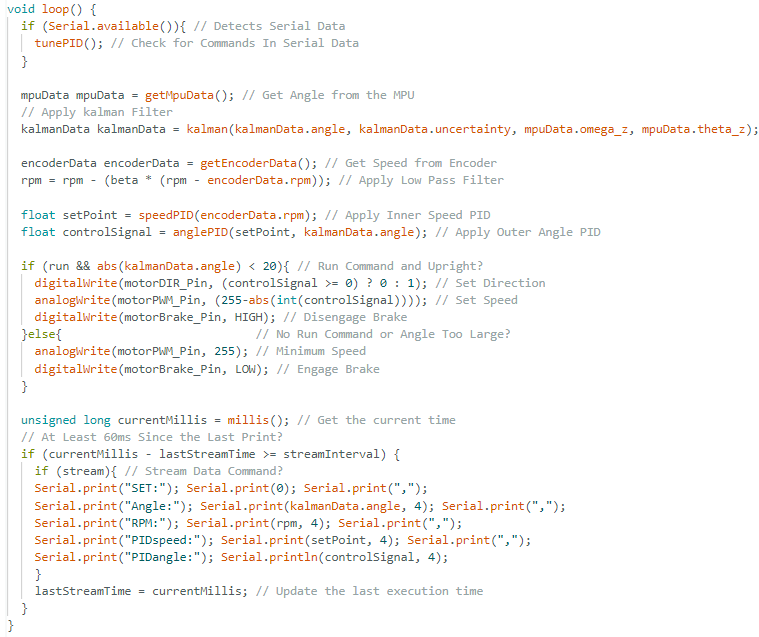
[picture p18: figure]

- 62 -

### 3.5.10 Overview

The final version of the project code included the Kalman filter to combine the MPU6050’s

accelerometer and gyroscope readings into an accurate angular position, a Cascaded PID control

loop where the inner loop adjusts the set point for the outer loop based on the speed of the reaction

wheel, an IF statement that checks for acceptable run and position values before moving the motor,

a custom function that accepts commands through the Serial Monitor to change PID gains, start

and stop the motor, and to start and stop streaming data, and a watchdog timer that only sends data

to be streamed after an acceptable interval.

Figure 46. Overview of Project Code.

The watchdog timer stops the program from being slowed down by excessive communication. It

was found that the printing data on every loop iteration would prevent the sensor reading from

moving smoothly as the microcontroller would miss live data as it was busy printing data.

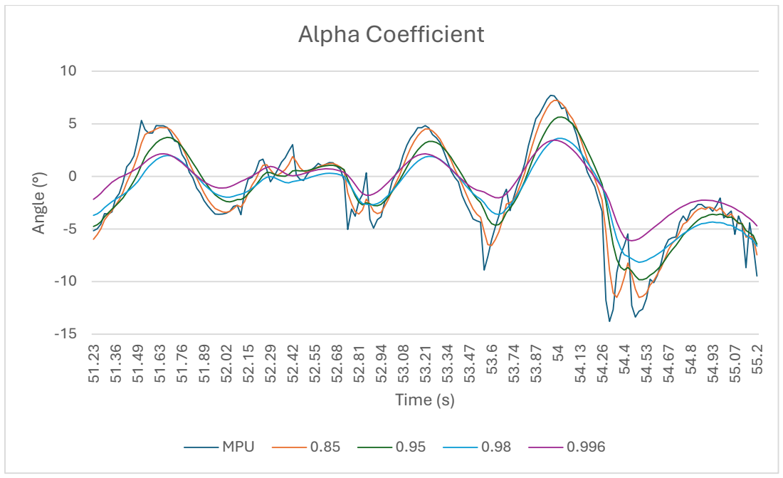
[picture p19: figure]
Angle (°); Time (s); Alpha Coefficient; MPU

- 63 -

### Chapter 4 Results and Discussion

This chapter offers an in-depth analysis and discussion of the various results derived from the

methods and techniques implemented throughout the project. The data is presented through visual

figures, and a comparison of the different methods and their outcomes is provided.

## 4.1 Complementary Filter

The complementary filter is designed to take a high sample rate from the gyroscope, to reduce

sensor noise, and a low sample rate from the accelerometer, to reduce sensor drift. The ratio

between these sample rates is called the alpha coefficient, from Equation 2.14, and is best defined

through experimentation on the specific rig. The results for this mechanical build are shown in

Figure 47.

Figure 47. Complementary Filter Alpha Coefficient Comparison.

From the data in the Alpha Coefficient graph, it is clear to see that the raw angle read from the

MPU6050s accelerometer, without input from the gyroscope, is too noisy. The Complementary

Filter goes a good job at combining the two sensor readings, but the sensor reading was still affected

by the accelerometers noise at 0.85 and 0.95. Not until a very high ratio 0.98, was a clear reading

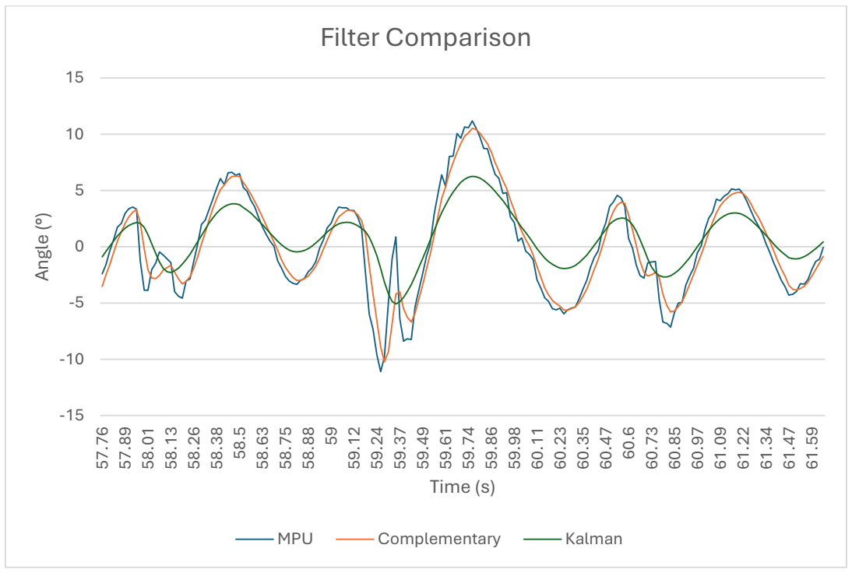
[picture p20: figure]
Angle (°); Time (s); Filter Comparison; MPU; Complementary; Kalman

- 64 -

attained, showing responsive and smooth transitions. Higher values like 0.996 are shown to lose

response time, and thus not respond to the same magnitude.

## 4.2 Kalman Filter

The Kalman filter also combines high-frequency gyroscope readings with low-frequency

accelerometer data to reduce noise and drift. However, unlike the complementary filter, it further

improves accuracy by incorporating the uncertainty from the previous step, allowing it to predict

the next state with greater confidence. This prediction step helps refine sensor fusion and provides

more reliable estimates of the system's state.

Figure 48. Comparison of Complementary and Kalman Filters.

From the graph comparing filters in Figure 48, it can be seen that the complementary filter is still

affected by noise at times, this will affect the output of the control algorithm leading to instability.

The Kalman filter, although appearing less responsive, provides a smooth output without sudden

spikes in opposing directions, mimicking the motion of the mechanical build during testing. The

lower magnitude of the Kalman filter could be due to the removal of the noise from the system,

resulting in a less exaggerated, more accurate positional reading during and after motion.

- 65 -

## 4.3 Single Loop PID Control

Through excruciating trial and error, the best response to PID control was achieved by increasing

the magnitude of the positional error by ten-fold. Slightly counterintuitive because if the gains were

ten-fold then the output should be the same, but this is not the case due to the nature of the floating-

point variable the error is stored as. Multiplying the error by ten gives the lower order numbers,

those further to the right of the decimal, in the error more weight when the gains are applied, leading

to a more precise input and thus result.

Figure 49. Error for Single Loop PID Control

The option to set the target angle was also necessitated during this phase, as the IMU was

discovered to be displaying an offset of its own, either through the mounting of the sensors on the

breakout or through the mounting of the module itself onto the structure. Either way, the ability to

adjust the target angle by a fraction of a degree through Serial Monitor commands helped in being

able to define zero for the PID positional control loop.

### 4.3.1 Single Loop Proportional Control

Figure 50 shows the angle from the true upright position of the mechanical build. The angle is

mapped against time for increasing values of proportional gain. Figure 51 shows the corresponding

proportional control output for the angles. The range of values for gain were chosen for their

obvious visual impact on the system. Note the inversion of the output signal to the angle, to

counteract the falling of the system into the opposite direction. Note also how the lower gain graph

remains somewhat the same on both graphs, whereas the larger gain is clearly exaggerated on the

proportional output graph compared to the angle graph. This highlights the effect the proportional

gain has on the control system.

A proportional gain of 2.85 was shown to be the largest value to have a negligible effect on the

falling system. Upping the gain to between 3.5 and 4.5, the system starts to show signs of control,

but unfortunately a value couldn’t be found to provide stability to the system. The value was

increased until an obviously overly proportional response was attained, in which the build was not

freely falling, but clearly being pushed out of balance by the reaction wheel, seen by 6.45.

Proportional gain alone was not enough to provide stability, aligning with simulations.

# PID Control - Proportional Gain

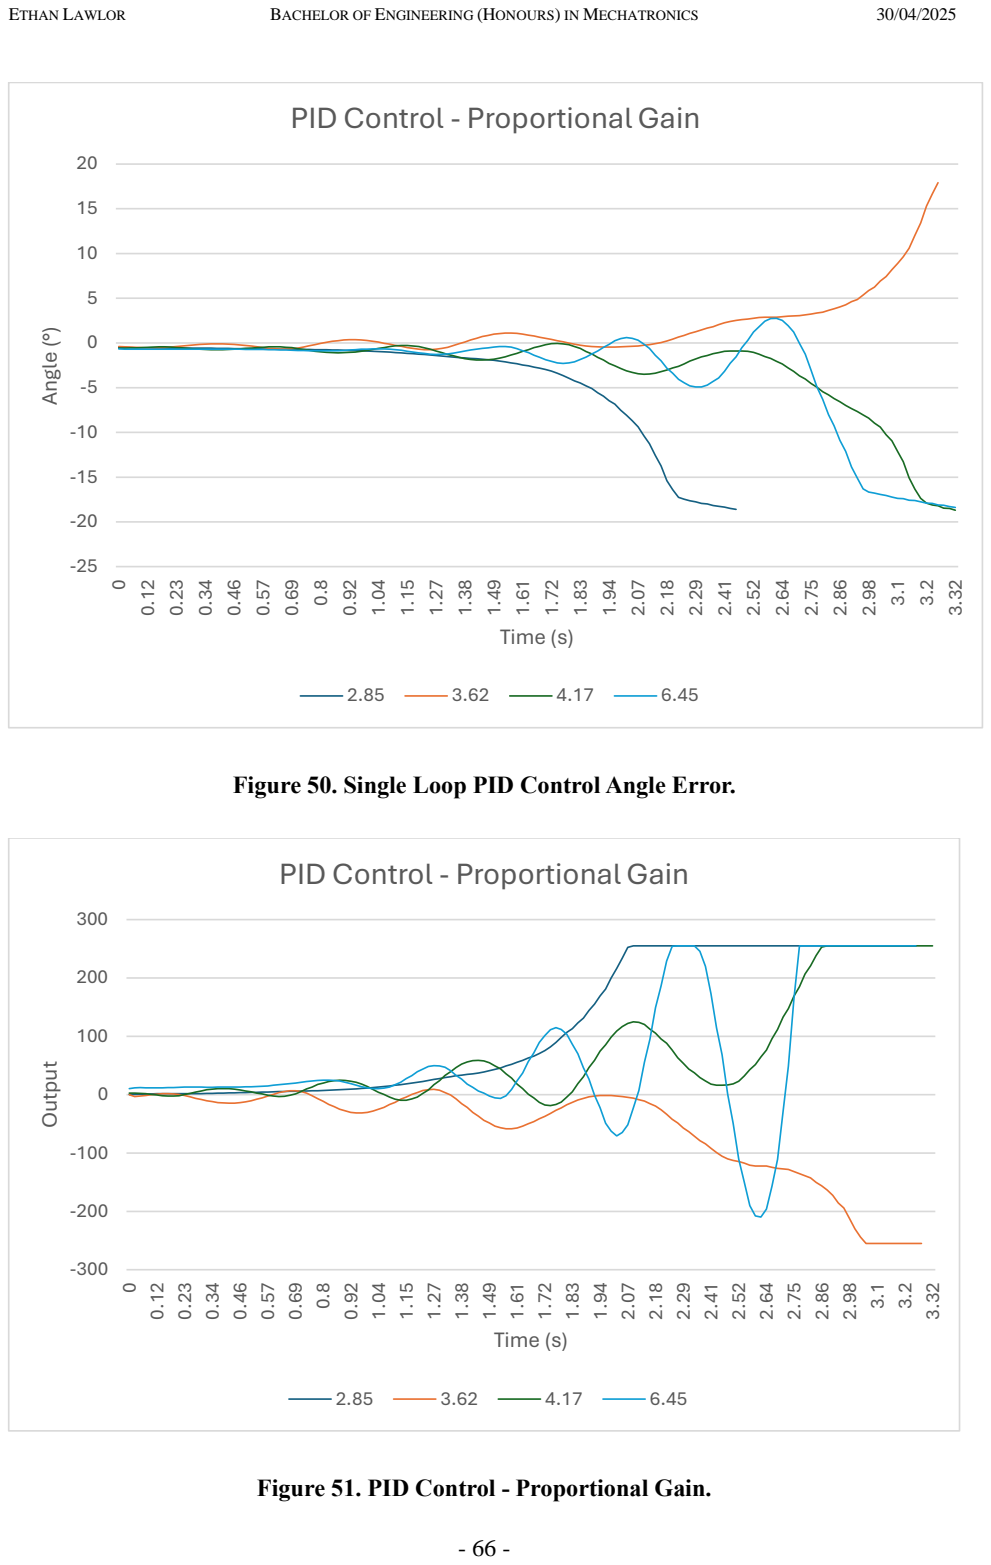
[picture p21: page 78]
Angle (°); Time (s); Output

Figure 50. Single Loop PID Control Angle Error.

PID Control - Proportional Gain

Figure 51. PID Control - Proportional Gain.

- 67 -

### 4.3.2 Single Loop Derivative Control

Derivative control was employed to add to the response by pre-empting the future state of the

system. Derivative control does this by applying a gain to the rate of change of the error. The results

for varying derivative gains are shown below in Figure 52. The graph shows both the Proportional,

and the Proportional-Derivative control response, highlighting the effect of the derivative gain on

the system to smooth the output.

Figure 52. PID Control - Derivative Gain.

The application of the lower derivative gain, 0.15, shows minimal deviation from the solely

proportional response. Increasing the gain to 0.3 shows a slight improvement in stability, while a

gain 0.5 resulted in the most stable output. Increasing the derivative gain to values larger than 0.7

resulted in more oscillations and inhibited the proportional gain from responding at a magnitude

that was sufficient to orientate the system.

Although the simulation showed Proportional-Derivative control would be substantial enough to

orientate the system, this is not the case with the mechanical build. Further control must be

explored.

- 68 -

### 4.3.3 Single Loop Integral Control

Integral control was included to improve stability. Integral gain is applied to the sum of the error,

usually to counteract steady state error in the output, in the case of a reaction wheel inverted

pendulum, it adds to the responses magnitude the more the pendulum leans in that direction. The

Proportional-Integral-Derivative control and the corresponding Proportional-Derivative control

outputs are graphed in Figure 53, showing the effect of the integral gain on the control systems

output.

Figure 53. PID Control - Integral Gain.

The addition of the integral gain to the system shows a clear increase in response, deviating more

from the Proportional-Derivative control as sum of the errors increases. The larger the integral gain,

the greater the deviation from the Proportional-Derivative curves as time goes on.

Increasing the integral gain hasn’t presented a clear pattern, a lower value of 0.1 and mid-range

values of 0.5 and 0.75 has produced a similar balancing time, while 0.3 and 0.9 also present a

similar balancing time. Incorporating Integral control hasn’t noticeably improved the overall

stability of the system, when compared to Proportional-Derivative control.

- 69 -

### 4.3.4 Single Loop PID Control

A number of trials of varying proportional, integral, and derivative gains were attempted and their

results graphed in Figure 54. A start point was taken from the previous values and manually tuned

from there. Other tuning methods require determining the critical gain and the period for the system,

which were unobtainable from the proportional gain alone.

Figure 54. Single Loop PID Control.

After sufficient trials and time, it was clear the Single Loop PID Control would not be enough to

stabilize the pendulum. The model is shown to balance for a brief period while swinging about zero

but eventually the wheels speed increases to such an extent that it cannot provide any more change

in speed to correct the alignment and the system falls. The wheel speed problem is called saturation

and indicates the wheel speed needs to be taken into consideration to make the control algorithm

more effective. In a zero-gravity environment the loop might be able to work, due to the removal

of the alternating potential energy, but this would need to be tested to be confirmed. It was decided

to move forward, building on this strategy with a Cascade loop.

- 70 -

## 4.4 Encoder Low-Pass Filter

The Cascade loop builds on the previous Single loop by altering its setpoint with a second nested

PID control loop. The error for the new PID loop is the speed of the reaction wheel as read by the

encoder. The encoder raw data was seen to be affected by noise, either from interrupts service

routines overlapping each other, or due to the vibration caused by the motor, and therefore required

filtering. A Low-Pass filter was implemented to remove smooth the data from the sensor. The

results of various coefficients for the low-pass filter are shown below.

Figure 55. Encoder Low-Pass Filter Coefficient Comparison.

The reading from the encoder is seen to be quite rough, a value of 0.2 does have an immediate

effect on the output but is still quite jagged in places where the motor speed is levelling out to

change direction or when the continuous changing speed starts to match the harmonic frequency of

the system and induces exceptionally large vibrations. This is also seen in a lesser degree in the

output of the 0.1 and 0.08 values. Not until the coefficient decreases to 0.05 does the data truly

begin to smooth out. Some responsiveness is lost, seen by 0.05 lagging behind the other curves on

the graph, but this was shown to not affect the overall performance of the system, while the

smoothness of the input data was shown to lead to a smooth control system output.

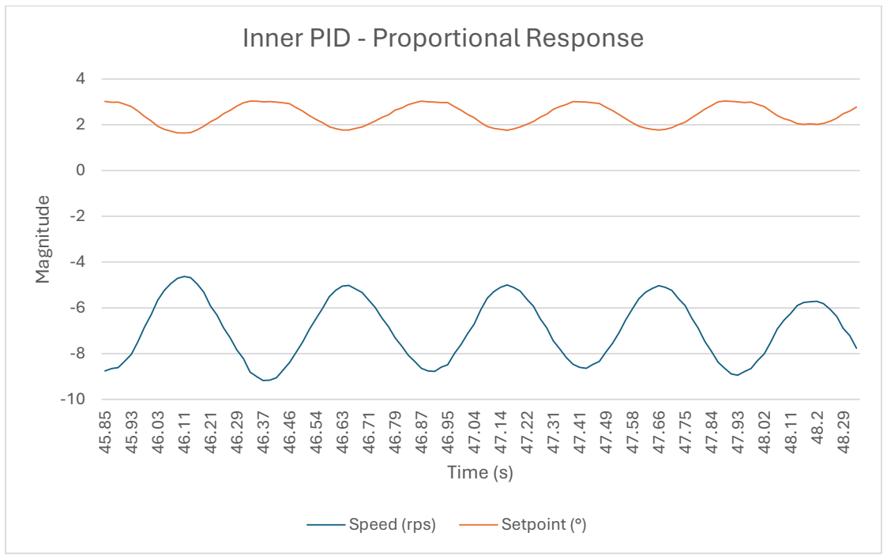
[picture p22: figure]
Magnitude; Time (s); Inner PID - Proportional Response; Speed (rps); Setpoint (°)

- 71 -

## 4.5 Cascade Loop PID Control

Now that the encoder data has been filtered and the wheel speed is free from noise, the data can be

used in the Inner Speed PID Loop as its error.

Figure 56. Errors For Cascade Loop PID Control.

The graph in Figure 57 shows how the speed of the reaction wheel is translated into a setpoint for

the Outer Angle PID Loop. The curves clearly show how the setpoint, in degrees, reacts

proportionally to the wheel speed. The wheel speed increases as the angle of deflection increases,

this leads to the Inner Speed PID Loop to move the setpoint of the Outer Angle PID Loop in the

opposite direction, increasing the inner loop’s error and thus its response.

Figure 57. Cascade Loop Input to Output.

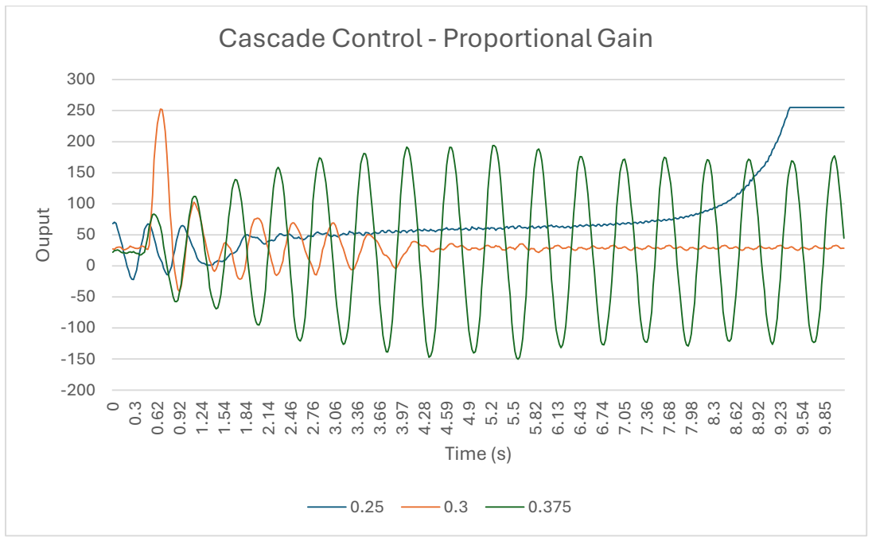
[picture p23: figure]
Ouput; Time (s); Cascade Control - Proportional Gain

- 72 -

### 4.5.1 Cascade Loop Proportional Control

The introduction of the proportional gain for the Inner Speed PID Loop immediately provided a

stable orientation. This stable orientation was maintained through an enormous range of values for

the inner loops proportional gain, not until a disturbance is introduced into the system does the

different gains produce different outputs. The Figure 58 displays the output of the Cascade Loop

for various inner loop gains during a disturbance. After brief experimentation it was found that the

Outer Angle PID Loop gains were best set as follows: aKp = 3.20, aKi = 0.00, aKd = 0.31.

Figure 58. Cascade Control - Proportional Gain.

The lower gain of 0.25 was shown to be able to correct a small initial disturbance, but wheel speed

saturation was still a problem. Increasing the gain to 0.3 solved the issue with wheel speed

saturation while also significantly increasing the size of the disturbance it was able to correct.

Increasing the gain again to 0.375 shows how higher values can magnify small disturbances to

induce oscillations in the system.

- 73 -

### 4.5.2 Cascade Loop Derivative Control

The Outer Speed PID Loops derivative gain was employed also to add to the response by pre-

empting the future state of the system to diminish the oscillations of the system and produce a

quicker settling time. The results for various derivative gains are shown in Figure 59, the other gains were set as follows: sKp = 0.30, aKp = 3.20, aKi = 0.00, aKd = 0.31.

Figure 59. Cascade Control - Derivative Gain.

A low gain of 0.001 was too small to completely dampen oscillations. Increasing the gain to 0.002

showed the oscillations gradually reduce in size and die out. A larger gain of 0.003 results in an

even larger initial response to the disturbance and was able to dampen it in an even quicker settling

time. Increasing the gain to large values induces oscillations even before the system is disturbed,

as shown by the 0.004 derivative gain curve.

- 74 -

### 4.5.3 Cascade Loop Integral Control

Integral control was again applied, this time to the Inner Speed PID Loop, to try improving overall

system stability. The results for the varying integral gains are shown in Figure 60, the results were

obtained while the other gains were set as follows: sKp = 0.30, sKd = 0.003, aKp = 3.20,

aKi = 0.00, aKd = 0.31.

Figure 60. Cascade Control - Integral Gain.

The introduction of the integral control into the inner loop, even at a small gain, has made improved

the response of the system but at the cost of its stability. While the disturbances are diminished

quickly by all values, the system continues to oscillate slightly, not settling to the same extent as

without integral control. This could be due to the ramping up and down of the sum of the errors of

the wheel speed as the pendulum sways past true zero. This ramping down of the value requires the

system to spend time past the upright position in the opposite direction, thus overshooting the mark

on every approach of zero.

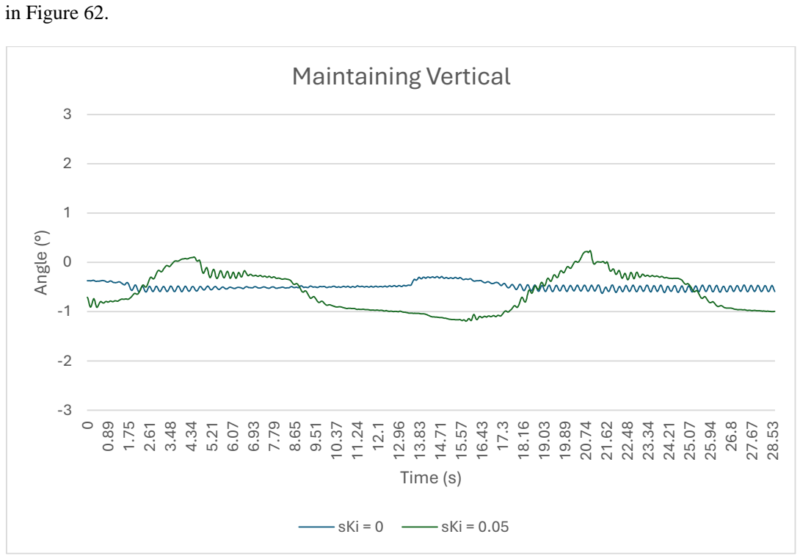
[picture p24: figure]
in Figure 62.; Angle (°); Time (s); Maintaining Vertical; sKi = 0; sKi = 0.05

- 75 -

### 4.5.4 Cascade Loop PID Control

The Cascade Loop, utilizing an Inner Speed and an Outer Angle PID loop, has been shown to exert

excellent control over the system. After going through each of the gains individually and observing

their effect on the overall system, the best parameters for maintaining a vertical position were found to be: sKp = 0.30, sKi = 0.00, sKd = 0.003, aKp = 3.20, aKi = 0.00, aKd = 0.31. This

combination of gains keeps the model upright with minimal deviation from the centre and offering

a certain amount of disturbance rejection. The range of the data is 0.41°, as seen in Figure 61, while

the disturbance rejection only has capacity to 100 out the possible 255 output for motor speed, seen

Figure 61. Maintaining Vertical - Cascade Loop Gain Comparison.

However, increasing the integral gain of the inner speed loop, even to just sKi = 0.05, will offer

better disturbance rejection at the cost of a slight drift about the vertical axis. The control loop now

has access to the full 255 output and can reject much larger disturbances, shown in Figure 61.

Unfortunately, the trade-off is the overall stillness of the system, seen by the range of the data in

Figure 61 increasing to 1.34°.

# Disturbance Rejection

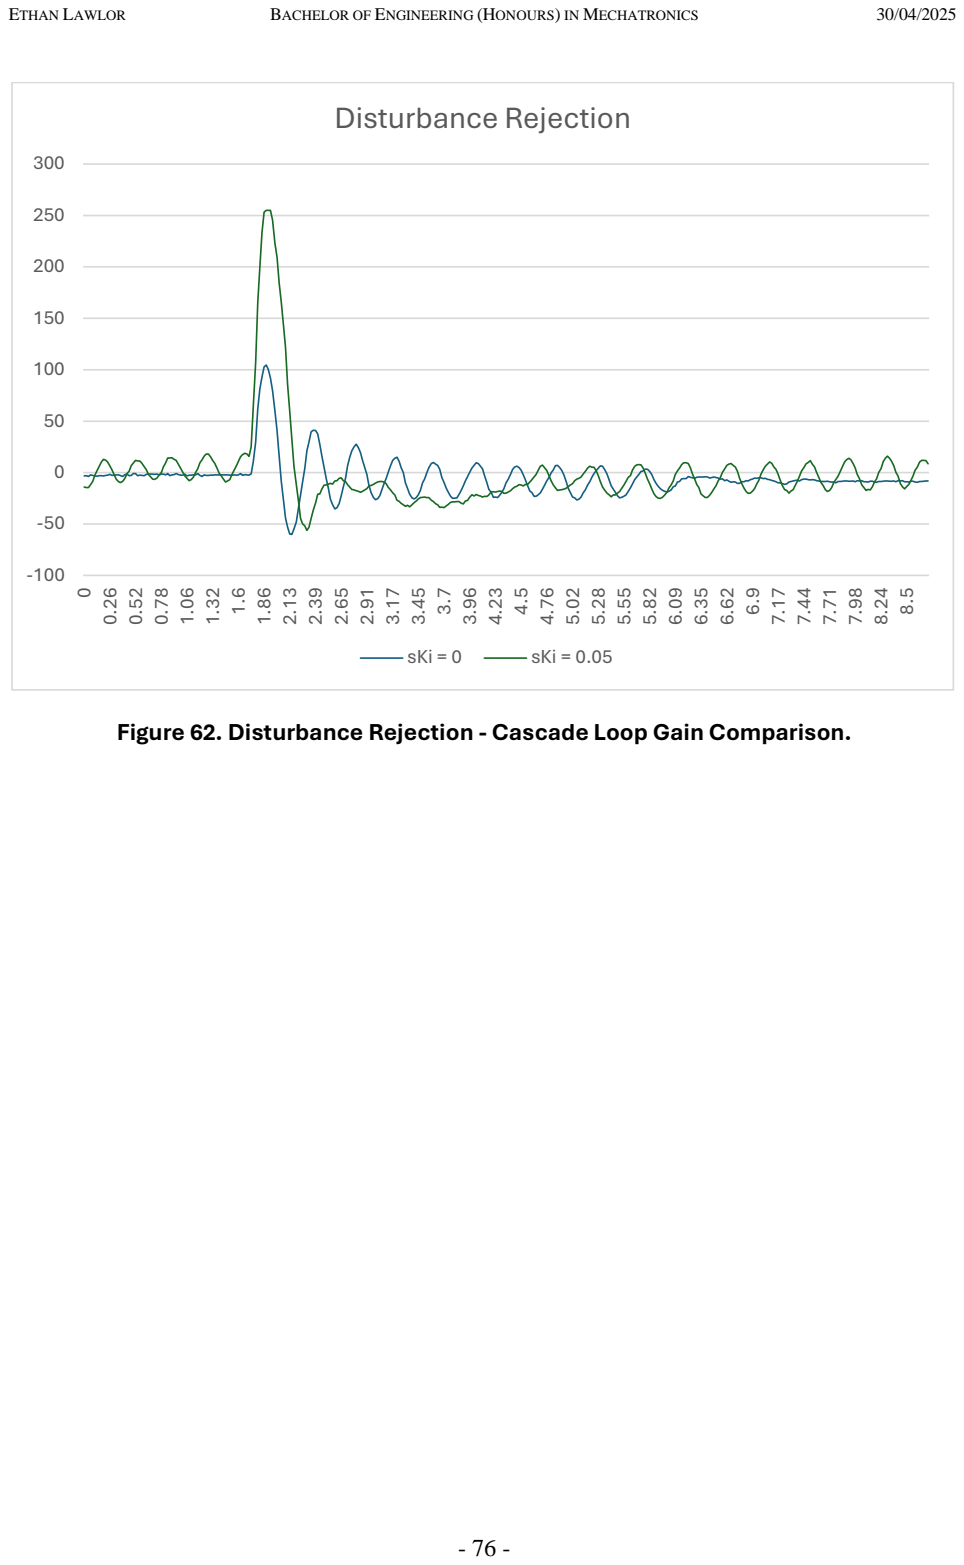
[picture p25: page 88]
sKi = 0; sKi = 0.05

Figure 62. Disturbance Rejection - Cascade Loop Gain Comparison.

- 77 -

### Chapter 5 Conclusions and Recommendations
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

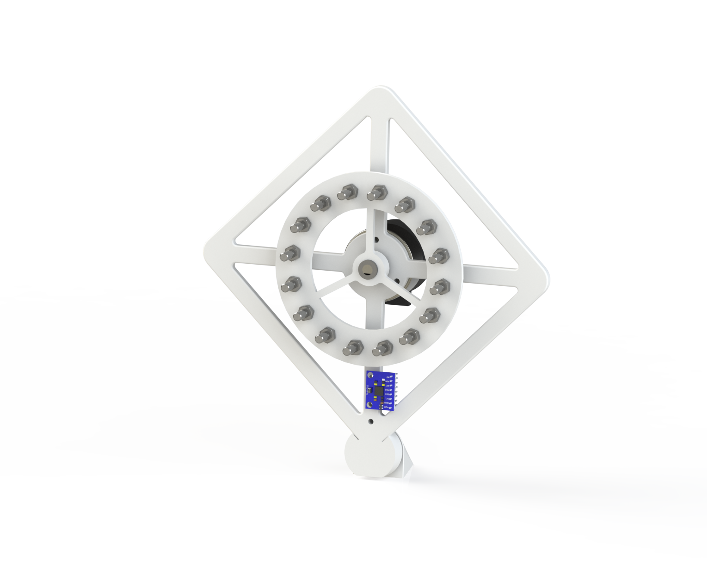
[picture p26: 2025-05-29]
2.Mechanical/Renders/Untitled.png

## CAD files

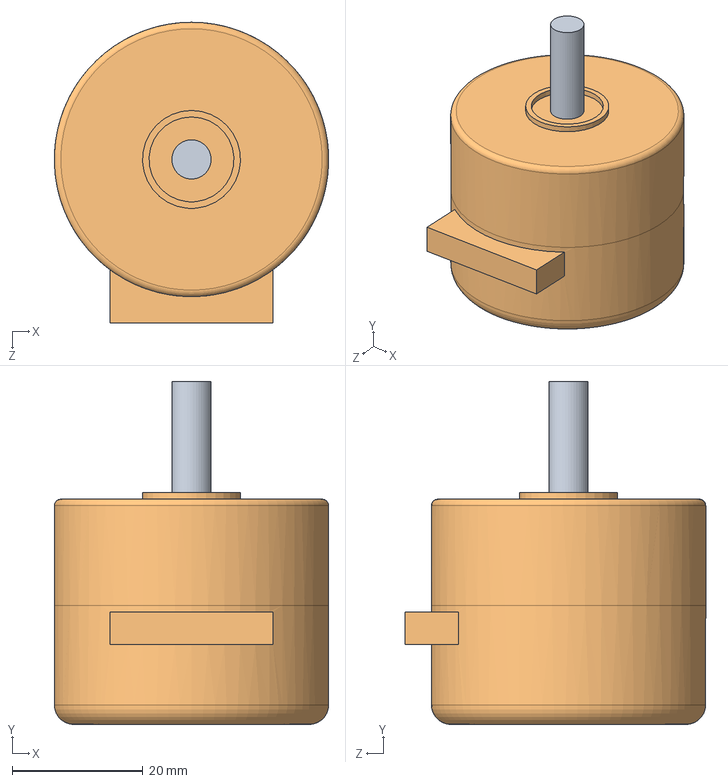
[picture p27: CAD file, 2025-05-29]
2.Mechanical/SolidWORKS/Nidec 24h.SLDASM
42.0 x 52.5 x 46.0 mm
Pin

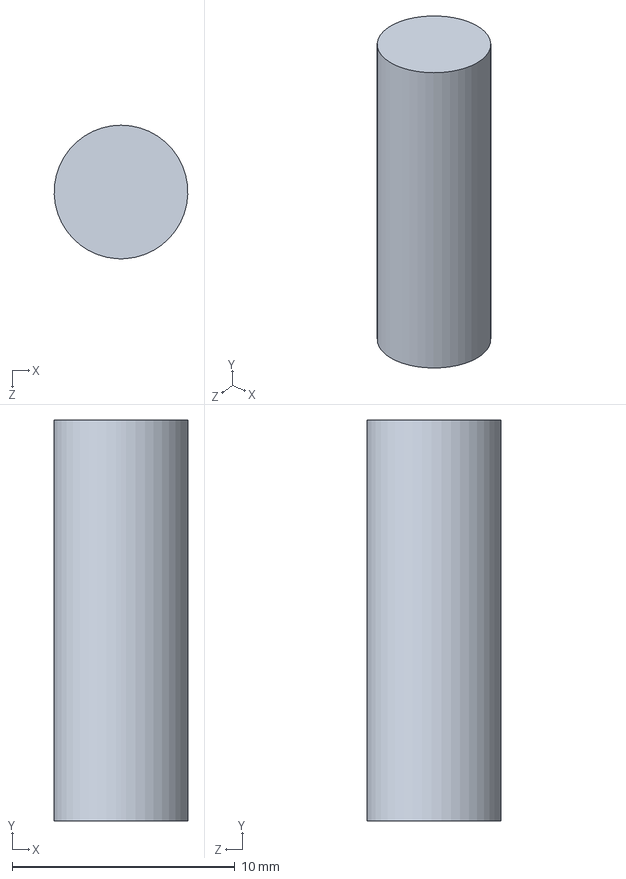
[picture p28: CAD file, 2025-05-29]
2.Mechanical/SolidWORKS/Pin.SLDPRT
6.00 x 18.0 x 6.00 mm

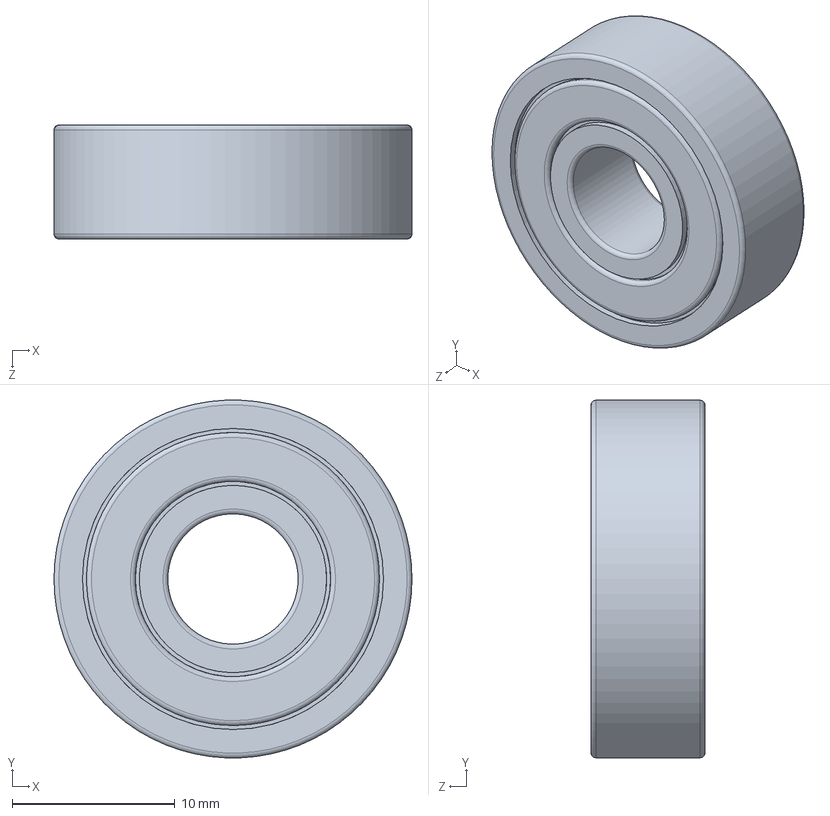
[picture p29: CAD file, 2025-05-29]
2.Mechanical/SolidWORKS/Skateboard_Bearing.SLDPRT
22.0 x 22.0 x 7.00 mm

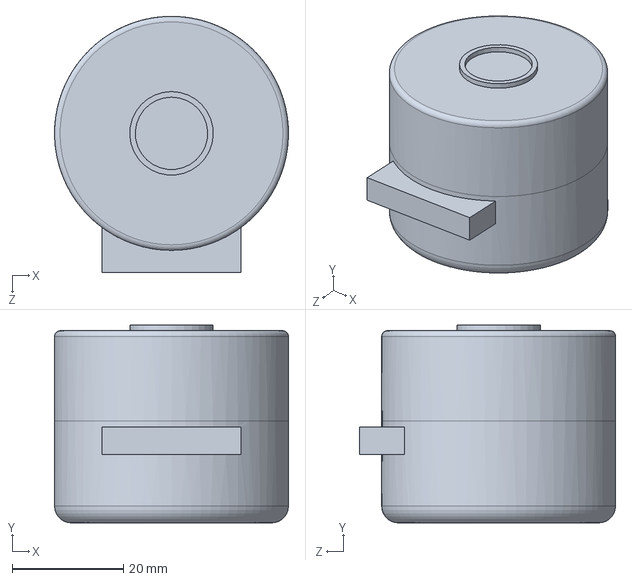
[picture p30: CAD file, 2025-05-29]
2.Mechanical/SolidWORKS/Body.SLDPRT
42.0 x 35.5 x 46.0 mm

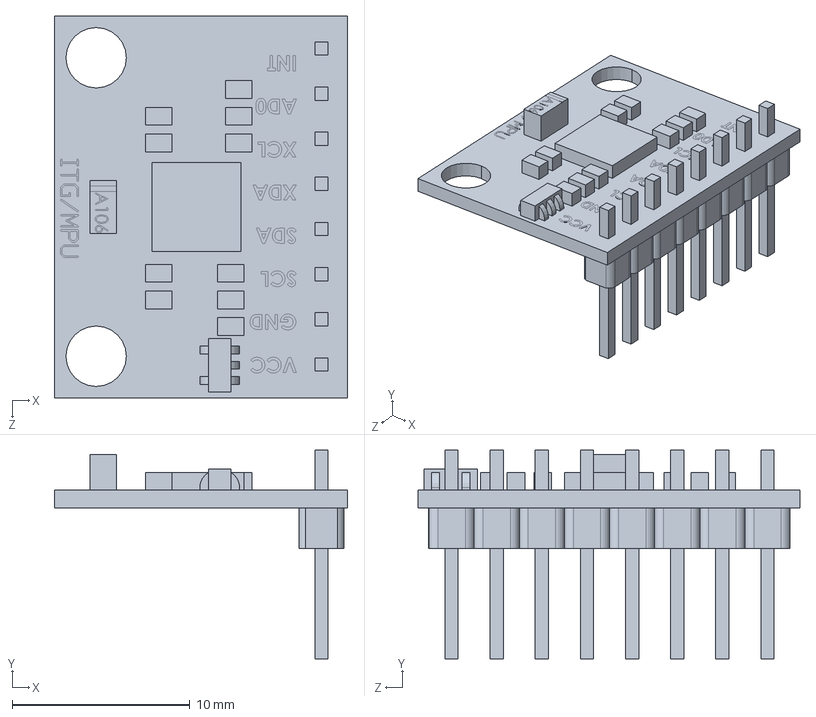
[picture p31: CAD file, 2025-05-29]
2.Mechanical/SolidWORKS/ITG-MPU.SLDPRT
16.5 x 11.8 x 21.5 mm

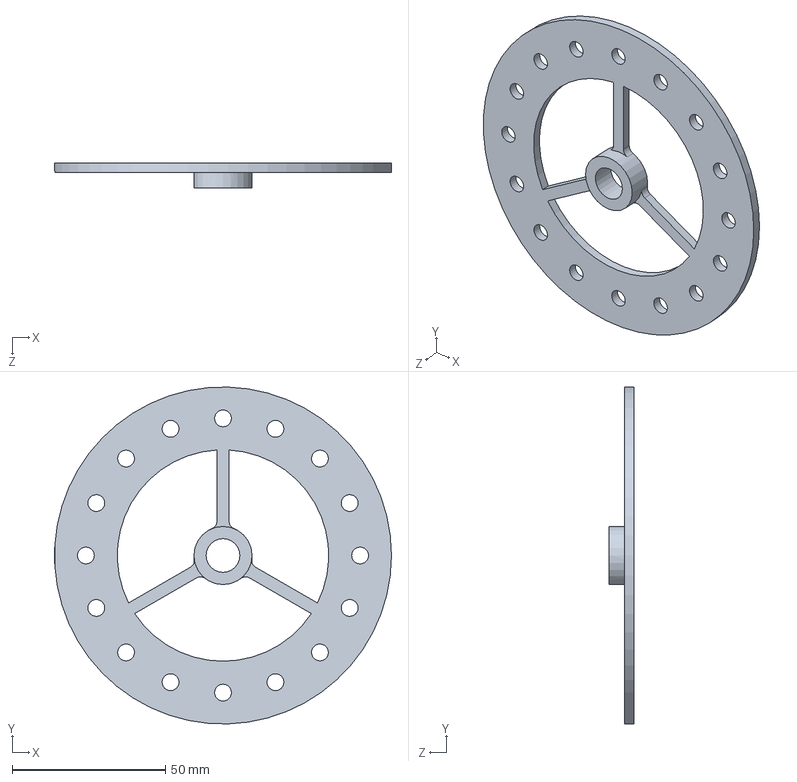
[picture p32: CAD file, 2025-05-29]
2.Mechanical/SolidWORKS/Flywheel.SLDPRT
110.0 x 110.0 x 8.00 mm

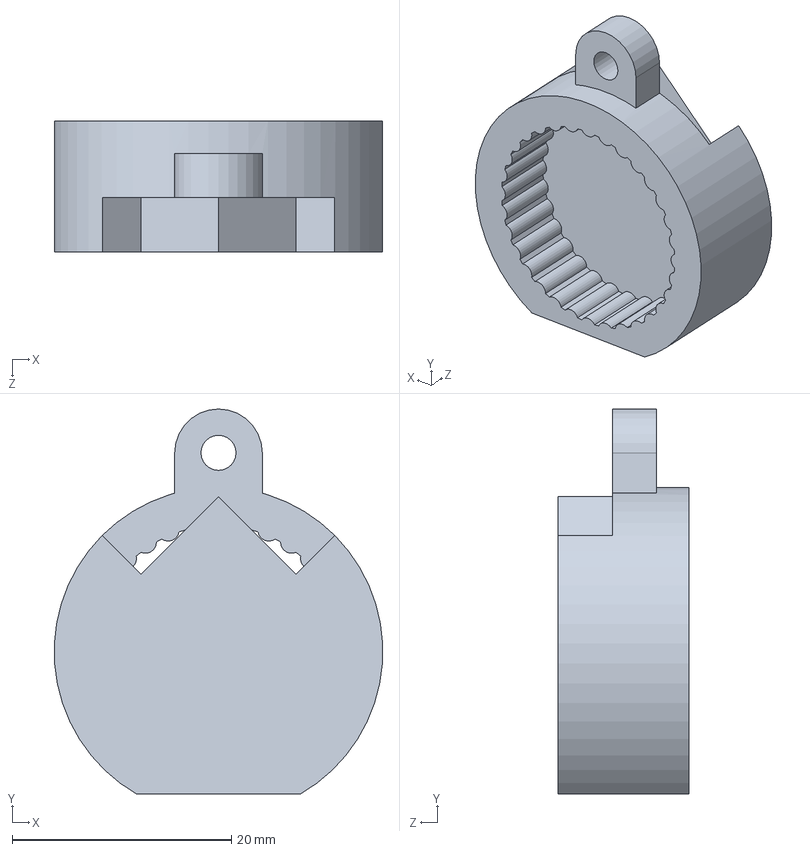
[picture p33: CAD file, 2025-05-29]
2.Mechanical/SolidWORKS/Pintle.SLDPRT
30.0 x 35.1 x 12.0 mm

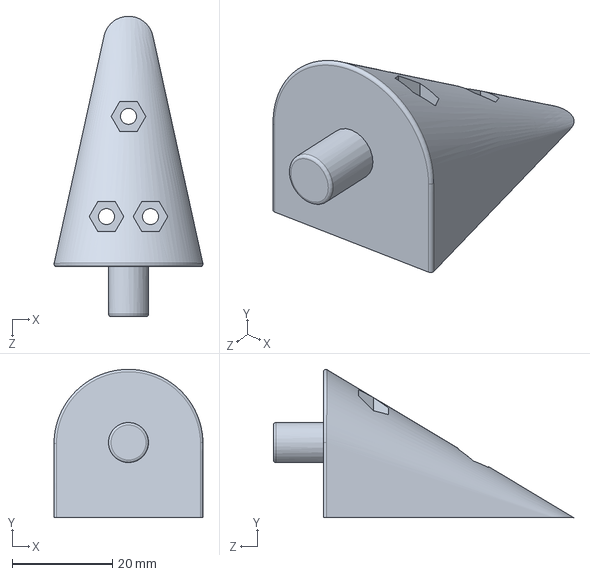
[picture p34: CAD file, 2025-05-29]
2.Mechanical/SolidWORKS/Gudgeon.SLDPRT
29.8 x 29.6 x 60.0 mm

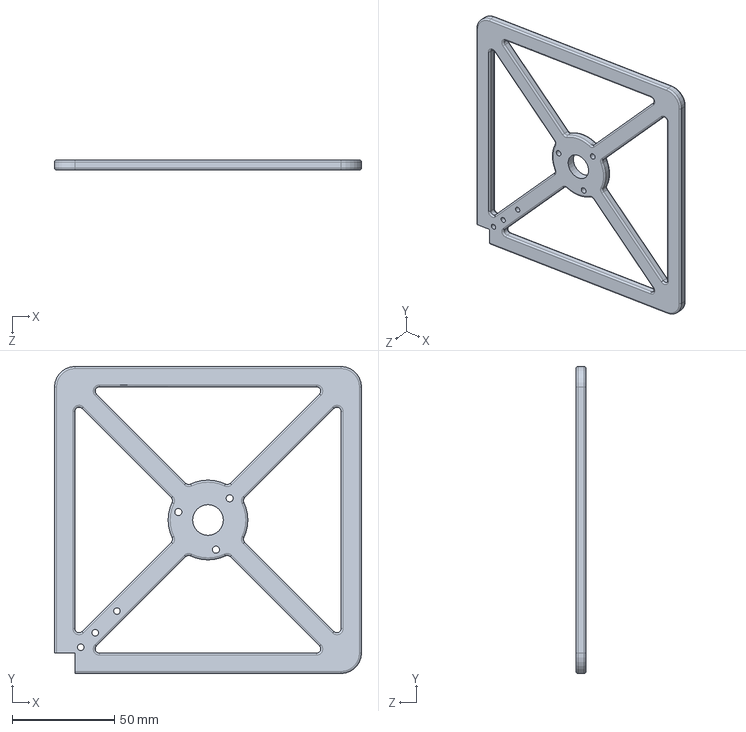
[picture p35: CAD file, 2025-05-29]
2.Mechanical/SolidWORKS/Face.SLDPRT
150.0 x 150.0 x 5.00 mm

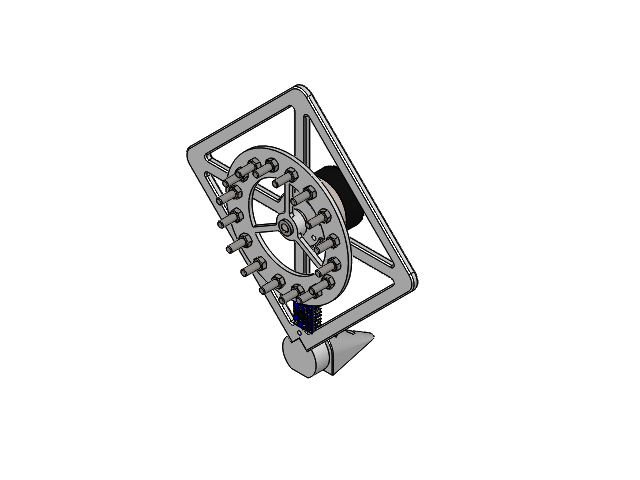
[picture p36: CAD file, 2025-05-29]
2.Mechanical/SolidWORKS/One Dimension - V3.SLDASM
Gudgeon
Pintle
Skateboard_Bearing
Flywheel
Pin
Spur
ITG-MPU
Part1^One Dimension - V3 x 16
Part2^One Dimension - V3 x 16

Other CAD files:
2.Mechanical/SolidWORKS/Spur.SLDPRT
2.Mechanical/STL/Flywheel.STL
2.Mechanical/STL/Gudgeon.STL
2.Mechanical/STL/Pintle.STL

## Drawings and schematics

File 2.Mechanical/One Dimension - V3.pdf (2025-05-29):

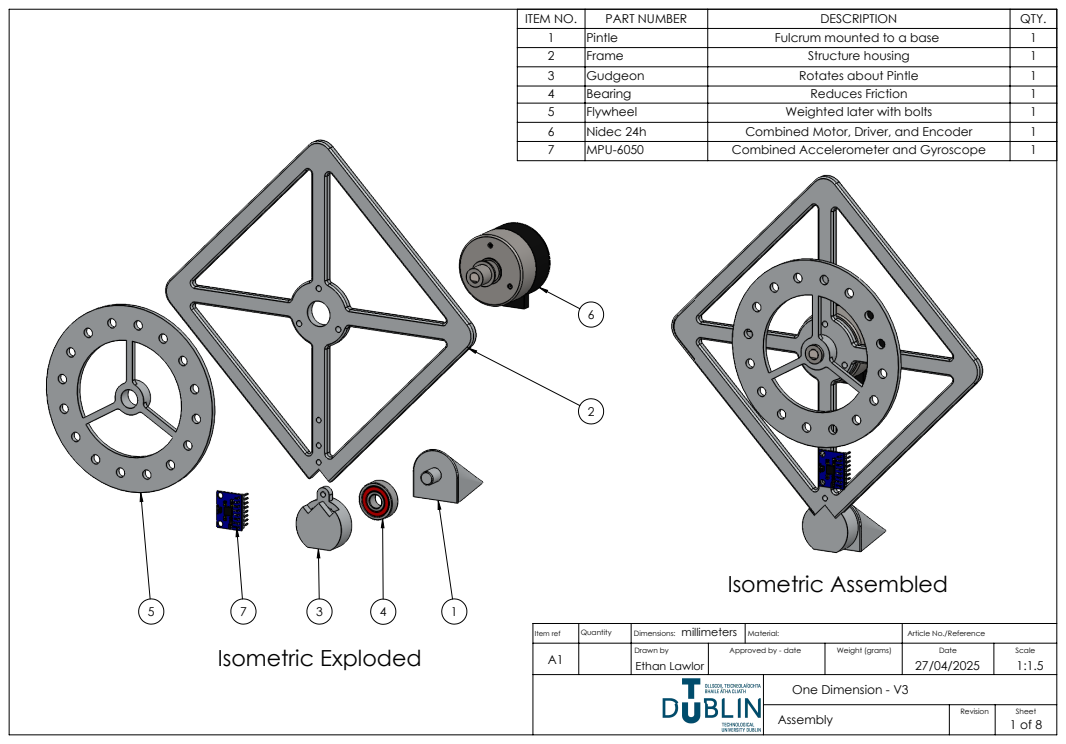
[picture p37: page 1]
Isometric Assembled; Isometric Exploded

ITEM NO. | PART NUMBER | DESCRIPTION | QTY.
1 | Pintle | Fulcrum mounted to a base | 1
2 | Frame | Structure housing | 1
3 | Gudgeon | Rotates about Pintle | 1
4 | Bearing | Reduces Friction | 1
5 | Flywheel | Weighted later with bolts | 1
6 | Nidec 24h | Combined Motor, Driver, and Encoder | 1
7 | MPU-6050 | Combined Accelerometer and Gyroscope | 1

Item ref | Quantity | millimeters Dimensions: | Material: | Article No./Reference

A1 | | Drawn by Ethan Lawlor | Approved by - date | Weight (grams) | Date 27/04/2025 | Scale 1:1.5

One Dimension - V3

Assembly | Revision | Sheet 1 of 8

SOLIDWORKS Educational Product. For Instructional Use Only.

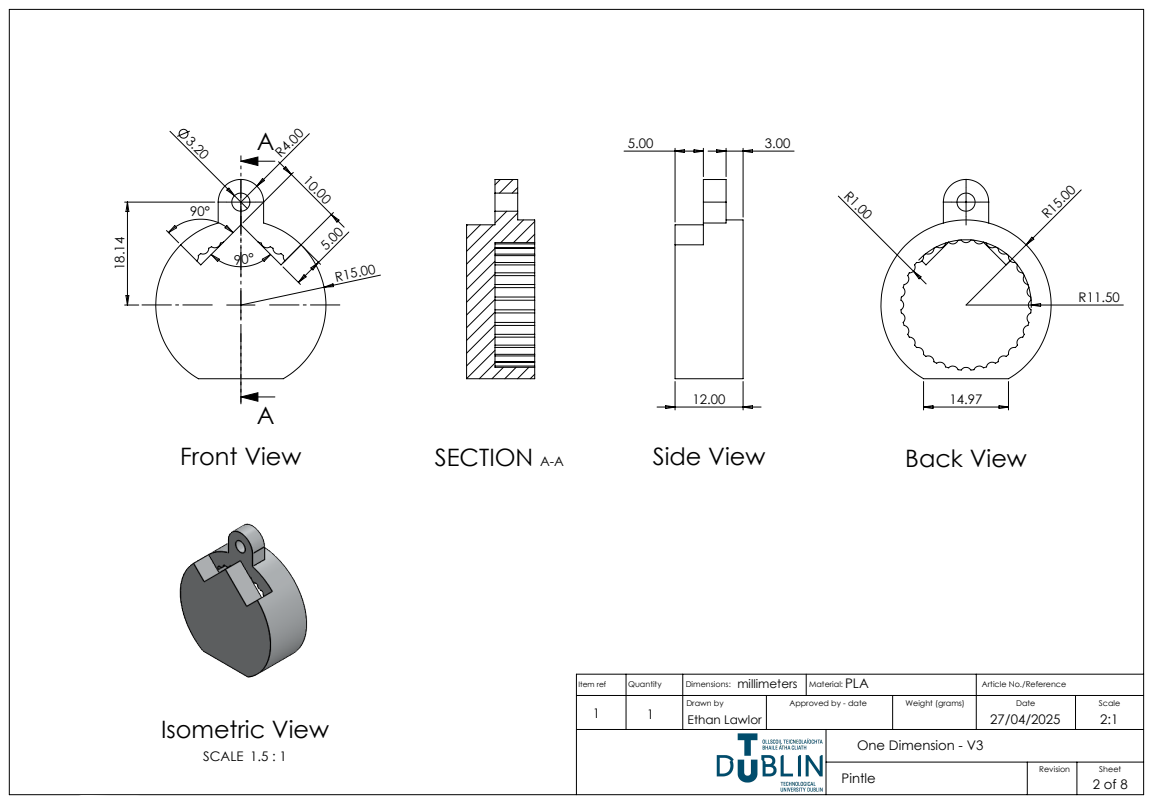
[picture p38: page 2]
Front View; Side View; SECTION A-A; Back View; Isometric View; SCALE 1.5 : 1

Item ref | Quantity | millimeters Dimensions: | PLA Material: | Article No./Reference

1 | 1 | Drawn by Ethan Lawlor | Approved by - date | Weight (grams) | Date 27/04/2025 | Scale 2:1

One Dimension - V3
Pintle | | 2 of 8

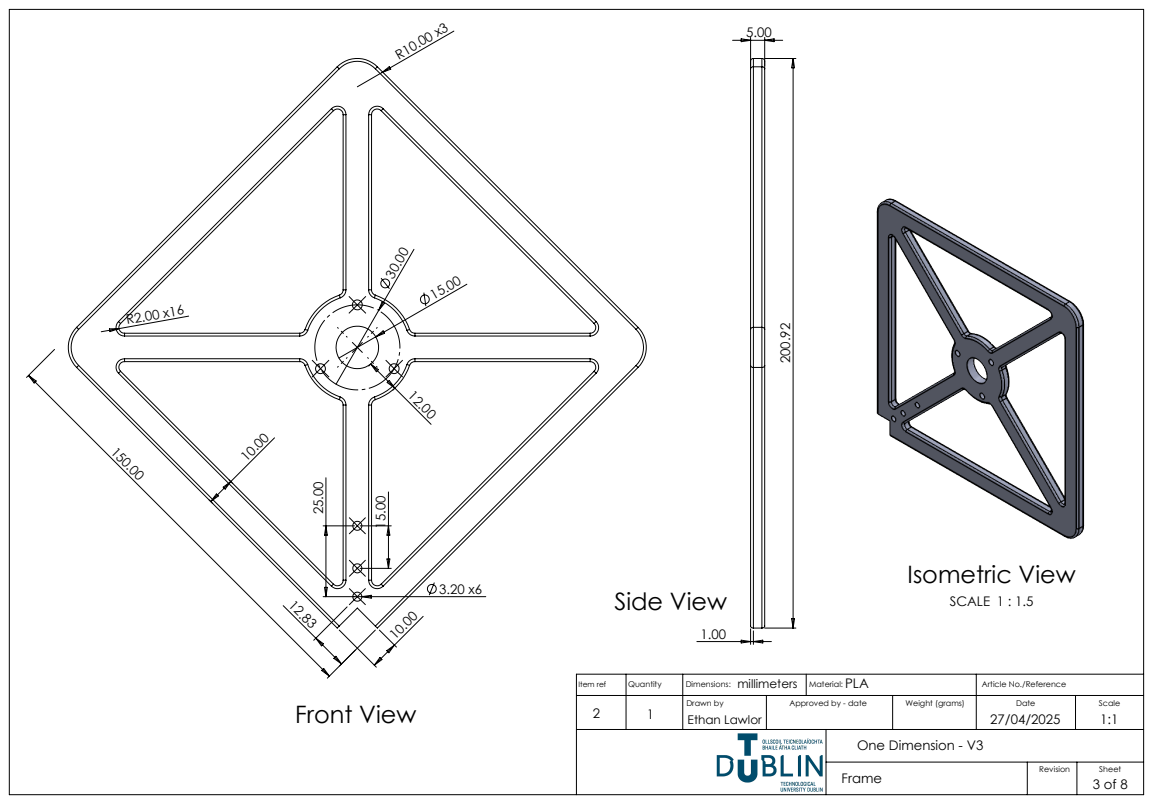
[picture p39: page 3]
Front View; Side View; Isometric View; SCALE 1 : 1.5

Item ref | Quantity | millimeters Dimensions: | PLA Material: | Article No./Reference

2 | 1 | Drawn by Ethan Lawlor | Approved by - date | Weight (grams) | Date 27/04/2025 | Scale 1:1

One Dimension - V3
Frame | | 3 of 8

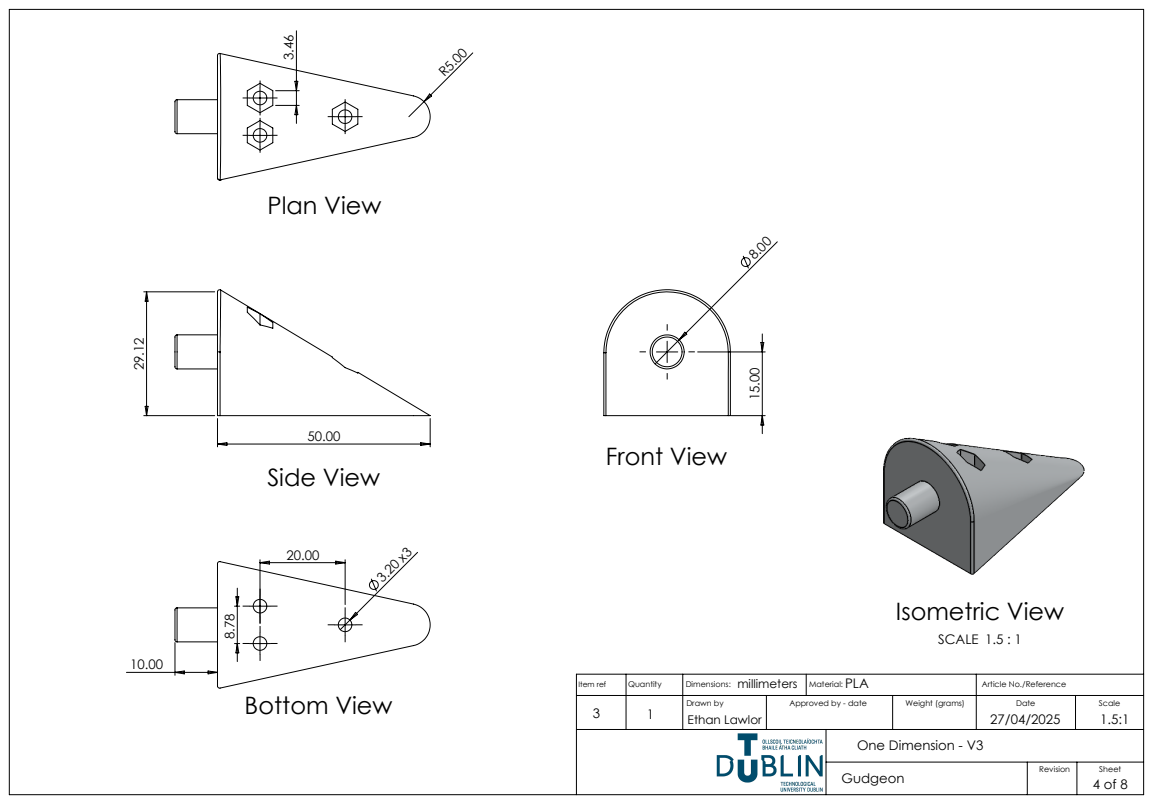
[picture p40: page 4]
Side View; Front View; Bottom View; Plan View; Isometric View; SCALE 1.5 : 1

Item ref | Quantity | millimeters Dimensions: | PLA Material: | Article No./Reference

3 | 1 | Drawn by Ethan Lawlor | Approved by - date | Weight (grams) | Date 27/04/2025 | Scale 1.5:1

One Dimension - V3
Gudgeon | | 4 of 8

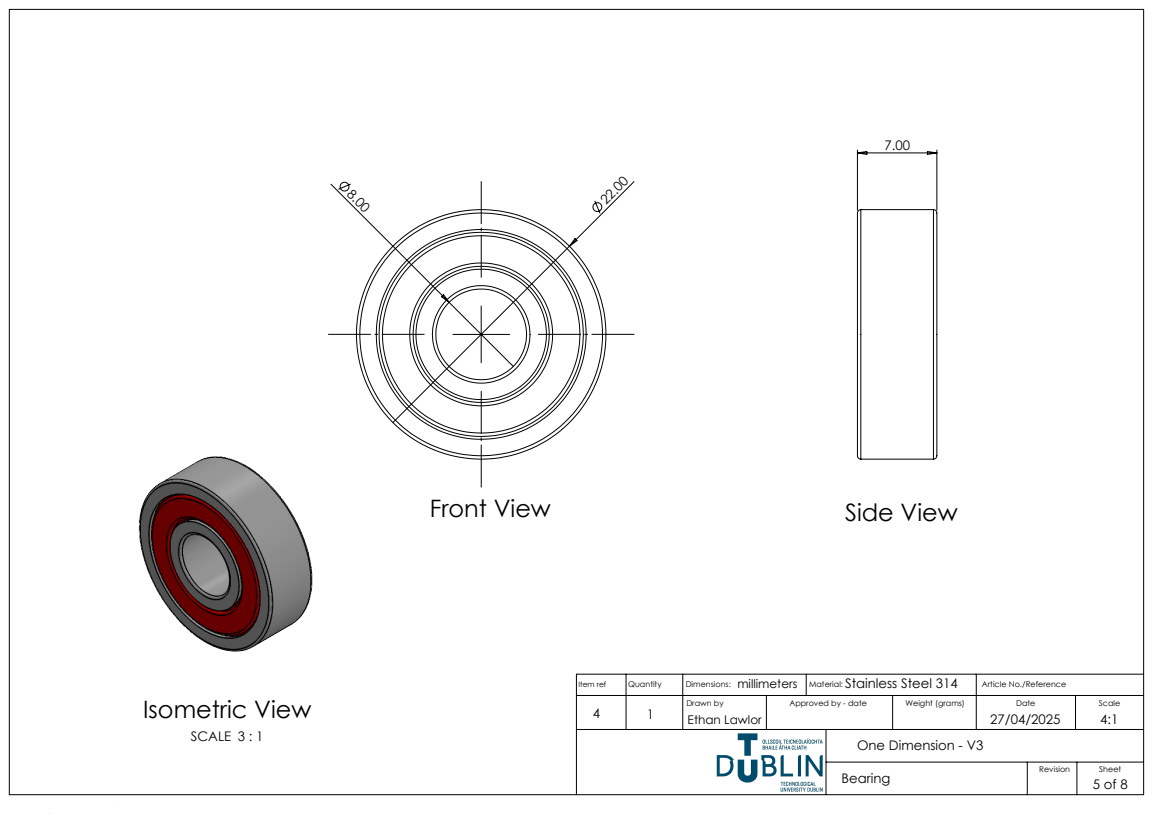
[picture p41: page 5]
Front View; Side View; Isometric View; SCALE 3 : 1

Item ref | Quantity | millimeters Dimensions: | Stainless Steel 314 Material: | Article No./Reference

4 | 1 | Drawn by Ethan Lawlor | Approved by - date | Weight (grams) | Date 27/04/2025 | Scale 4:1

One Dimension - V3
Bearing | | 5 of 8

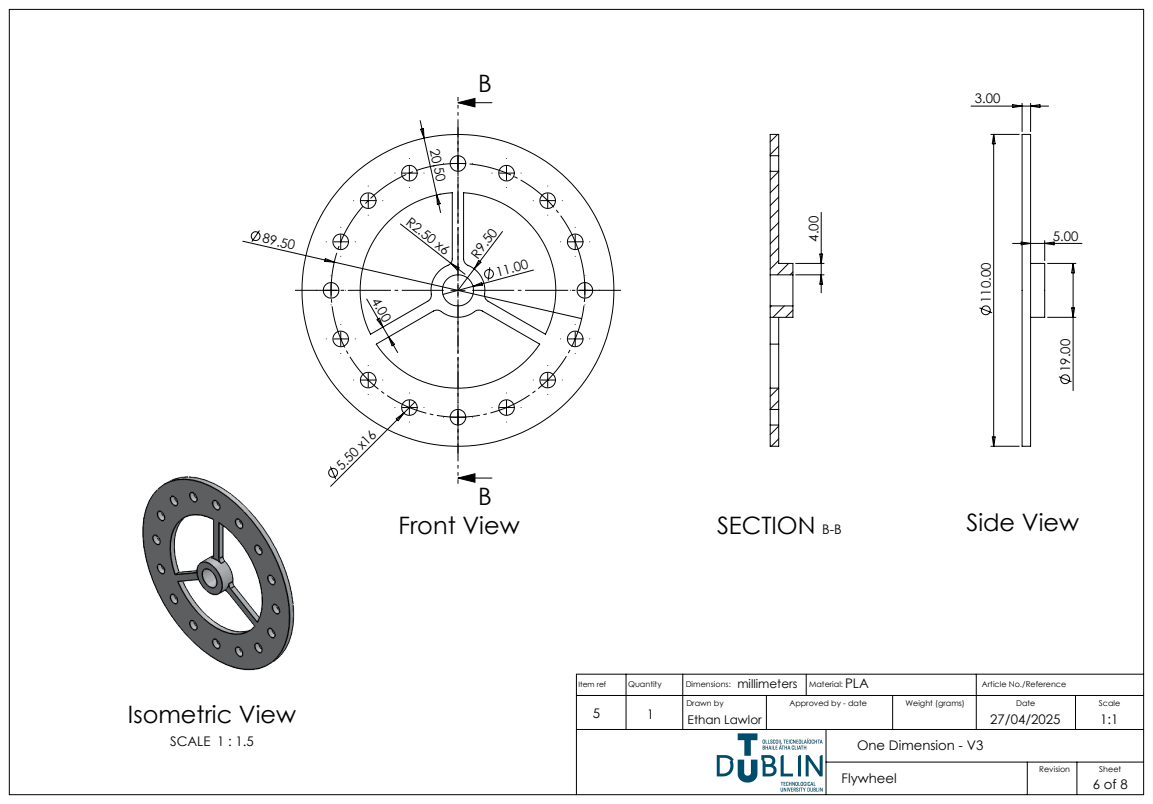
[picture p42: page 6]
Front View; Side View; SECTION B-B; Isometric View; SCALE 1 : 1.5

Item ref | Quantity | millimeters Dimensions: | PLA Material: | Article No./Reference

5 | 1 | Drawn by Ethan Lawlor | Approved by - date | Weight (grams) | Date 27/04/2025 | Scale 1:1

One Dimension - V3
Flywheel | | 6 of 8

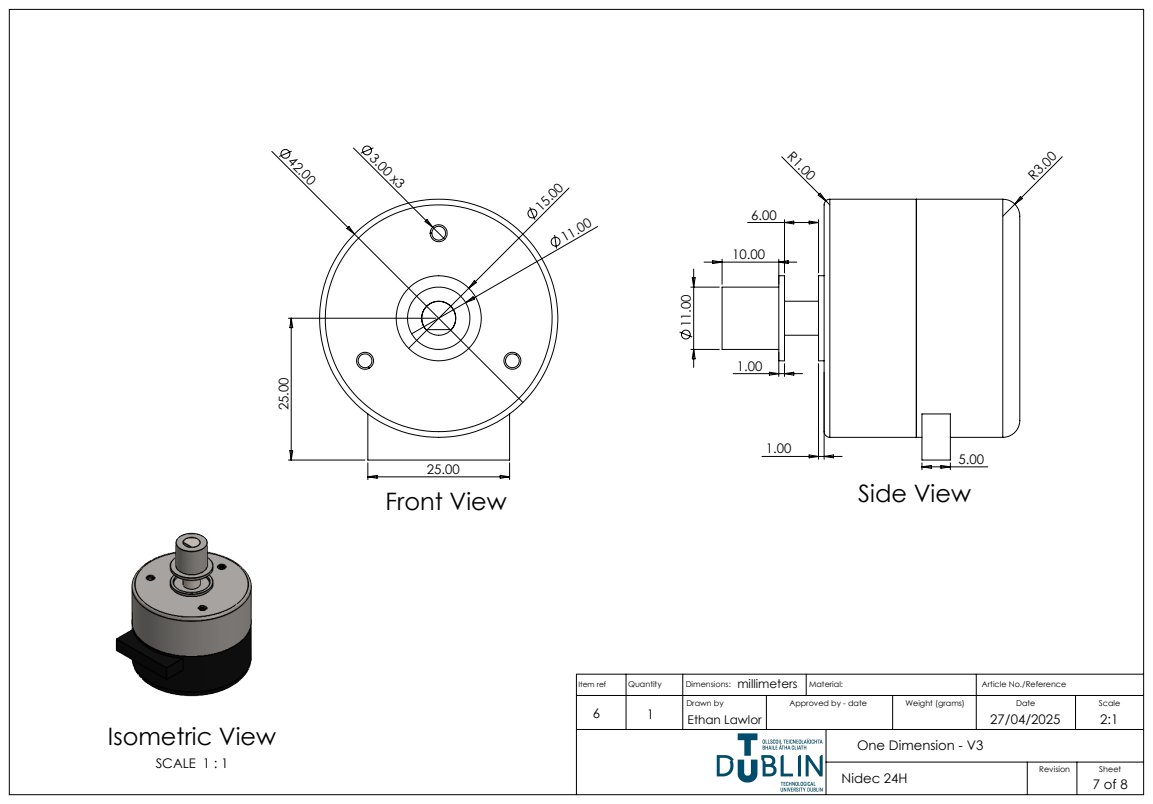
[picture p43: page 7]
Front View; Side View; Isometric View; SCALE 1 : 1

Item ref | Quantity | millimeters Dimensions: | Material: | Article No./Reference

6 | 1 | Drawn by Ethan Lawlor | Approved by - date | Weight (grams) | Date 27/04/2025 | Scale 2:1

One Dimension - V3
Nidec 24H | | 7 of 8

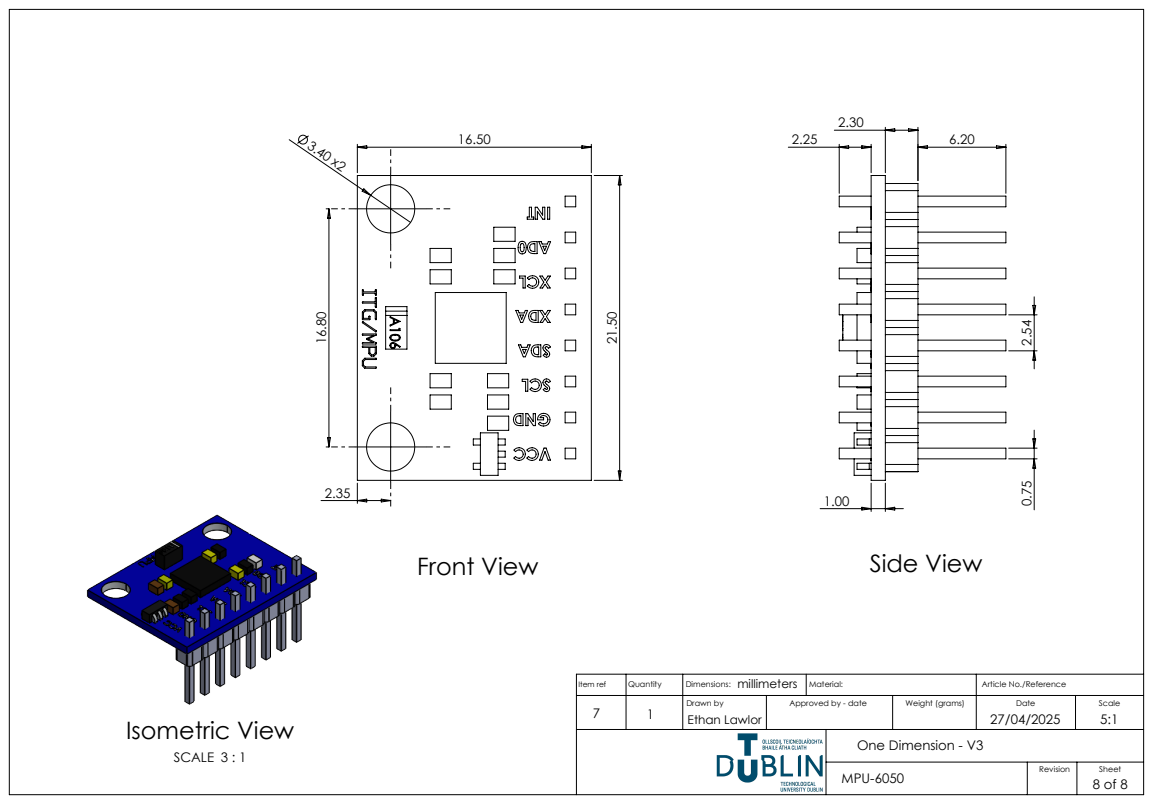
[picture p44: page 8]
Front View; Side View; Isometric View; SCALE 3 : 1

Item ref | Quantity | millimeters Dimensions: | Material: | Article No./Reference

7 | 1 | Drawn by Ethan Lawlor | Approved by - date | Weight (grams) | Date 27/04/2025 | Scale 5:1

One Dimension - V3
MPU-6050 | | 8 of 8

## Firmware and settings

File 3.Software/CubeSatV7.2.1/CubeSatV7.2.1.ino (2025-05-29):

/*
  Reaction Wheel Inverted Pendulum

  Cascade Loop - Speed of Motor as Outer, Angle From Vertical as Inner

  Ethan Lawlor - B00149346
  28/03/2025
*/

//#define DEBUG_ENCODER
//#define DEBUG_SPEED_PID
//#define DEBUG_ANGLE_PID

// MPU6050 Globals ---------------------------------------------------------------------------------
#include <Wire.h>          // Include the Wire library for I2C communication
#include <MPU6050.h>        // Include the MPU6050 library

MPU6050 mpu;
int16_t ax, ay, az, gx, gy, gz;
float gz_offset = 0;

struct mpuData {
  float theta_z;
  float omega_z;
};
// -------------------------------------------------------------------------------------------------

// Encoder Globals ---------------------------------------------------------------------------------
volatile long counter = 0;  
long lastCounter = 0;
unsigned long lastMillis = 0; 

struct encoderData {
  float rpm;
  bool direction;
};
// -------------------------------------------------------------------------------------------------

// Motor Globals -----------------------------------------------------------------------------------
#include <PWM.h>
#define Nidec_Frequency 30000
#define motorPWM_Pin 9
#define motorDIR_Pin 10
#define motorBrake_Pin 11
int motorPWM = 255;
bool motorDIR = 0;
// -------------------------------------------------------------------------------------------------

// LED Globals -------------------------------------------------------------------------------------
#define LED_PIN 13
bool blinkState = false;
// -------------------------------------------------------------------------------------------------

// Speed PID Globals -------------------------------------------------------------------------------
float sKp, sKi, sKd;
float sTarget = 0, sLastErr = 0, sErrSum = 0, sErrOrderF = 0, sErrOrderFprev = 0, sErrorPrev = 0;
double sLastTime;
// -------------------------------------------------------------------------------------------------

// Angle PID Globals -------------------------------------------------------------------------------
float aKp, aKi, aKd;
float aLastErr = 0, aErrSum = 0, aErrOrderF = 0, aErrOrderFprev = 0, aErrorPrev = 0;
double aLastTime;
// -------------------------------------------------------------------------------------------------

// Main Loop Globals -------------------------------------------------------------------------------
#include <EEPROM.h>
float angle = 0;
float alpha = 0.996;
float beta = 0.996;
float rpm;
float controlSpeed;
float controlAngle;
bool run = true;
bool stream = false;
unsigned long compTimeLast = 0;
// -------------------------------------------------------------------------------------------------

float RateRoll, RatePitch, RateYaw;
float RateCalibrationRoll, RateCalibrationPitch, RateCalibrationYaw;
int RateCalibrationNumber;
float AccX, AccY, AccZ;
float AngleRoll, AnglePitch, AngleYaw;
uint32_t LoopTimer;

float KalmanAngleRoll=0, KalmanUncertaintyAngleRoll=2*2;
float KalmanAnglePitch=0, KalmanUncertaintyAnglePitch=2*2;
float KalmanAngleYaw=0, KalmanUncertaintyAngleYaw=2*2;
float Kalman1DOutput[]={0,0};
void kalman_1d(float KalmanState, float KalmanUncertainty, float KalmanInput, float KalmanMeasurement) {
  KalmanState=KalmanState+0.004*KalmanInput;
  KalmanUncertainty=KalmanUncertainty + 0.004 * 0.004 * 4 * 4;
  float KalmanGain=KalmanUncertainty * 1/(1*KalmanUncertainty + 3 * 3);
  KalmanState=KalmanState+KalmanGain * (KalmanMeasurement-KalmanState);
  KalmanUncertainty=(1-KalmanGain) * KalmanUncertainty;
  Kalman1DOutput[0]=KalmanState; 
  Kalman1DOutput[1]=KalmanUncertainty;
}

void setup() {
  Serial.begin(38400);
  Serial.println("<Arduino Initializing>");

  motorInit();  // Initialize motor
  encoderInit();  // Initialize encoder and interrupts
  mpuInit();  // Initialize mpu
  pidInit();  // Initialize PID variables with EEPROM

  Serial.println("<Arduino Ready>");
  delay(500);
}

void ai0() {
  // Interrupt for pin 2 (A signal)
  if (digitalRead(3) == LOW) {
    counter++;  // Counter increments if B signal is LOW
  } else {
    counter--;  // Counter decrements if B signal is HIGH
  }
}

void ai1() {
  // Interrupt for pin 3 (B signal)
  if (digitalRead(2) == LOW) {
    counter--;  // Counter decrements if A signal is LOW
  } else {
    counter++;  // Counter increments if A signal is HIGH
  }
}

void loop() {
  if (Serial.available()){
    tunePID();
  }

  
  gyro_signals();
  RateYaw-=RateCalibrationYaw;

  kalman_1d(KalmanAngleYaw, KalmanUncertaintyAngleYaw, RateYaw, AngleYaw);
  KalmanAngleYaw=Kalman1DOutput[0]; 
  KalmanUncertaintyAngleYaw=Kalman1DOutput[1];



  //mpuData mpuData = getMpuData();

  //unsigned long compTime = millis() - compTimeLast; compTimeLast = millis();

  //angle = alpha*(angle + (mpuData.omega_z * (compTime/1000.0))) + ((1-alpha)*mpuData.theta_z);

  angle = KalmanAngleYaw + 0.5 ;

  encoderData encoderData = getEncoderData();

  rpm = rpm - (beta * (rpm - encoderData.rpm));
  
  controlSpeed = speedPID();
  
  controlAngle = anglePID();

  if (run && abs(angle) < 20){    
    digitalWrite(motorDIR_Pin, (controlAngle >= 0) ? 0 : 1);
    analogWrite(motorPWM_Pin, (255-abs(int(controlAngle))));
    digitalWrite(motorBrake_Pin, HIGH);
  }else{
    analogWrite(motorPWM_Pin, 255);
    digitalWrite(motorBrake_Pin, LOW);
  }

  if (stream){    
    Serial.print("SET:"); Serial.print(0); Serial.print(",");
    Serial.print("Angle:"); Serial.print(angle, 4); Serial.print(",");
    Serial.print("RPM:"); Serial.print(rpm, 4); Serial.print(",");
    Serial.print("PIDspeed:"); Serial.print(controlSpeed, 4); Serial.print(",");
    Serial.print("PIDangle:"); Serial.println(controlAngle, 4);
  }

  


  while (micros() - LoopTimer < 4000);
  LoopTimer=micros();




}

float speedPID(){
  unsigned long sCurrentTime = millis();
  float sTime = (sCurrentTime - sLastTime)/1000;

  float sError = sTarget - rpm;

  sErrSum += sError * sTime;
  sErrSum = constrain(sErrSum, -50, 50);

  float sErrOrder = (sError - sLastErr) / sTime;
  sErrOrderF = (0.9 * sErrOrderFprev) + (0.1 * sErrOrder);
  sErrOrderFprev = sErrOrderF;

  float sPterm = sKp * sError;
  sPterm = constrain(sPterm, -3, 3);
  float sIterm = sKi * sErrSum;
  float sDterm = sKd * sErrOrder;

  float controlSpeed1 = sPterm + sIterm + sDterm;

  sLastErr = sError;
  sLastTime = sCurrentTime;
  
  #ifdef DEBUG_SPEED_PID
  Serial.print("sPterm:"); Serial.print(sPterm, 8); Serial.print(",");
  Serial.print("sIterm:"); Serial.print(sIterm); Serial.print(",");
  Serial.print("sDterm:"); Serial.println(sDterm);
  #endif

  return controlSpeed1;
}

float anglePID(){
  unsigned long aCurrentTime = millis();
  float aTime = (aCurrentTime - aLastTime)/1000;

  float aError = (controlSpeed - angle)*10;
  
  aErrSum += aError * aTime;
  aErrSum = constrain(aErrSum, -50, 50);

  float aErrOrder = ((aError - aLastErr) / aTime);
  aErrOrderF = (0.9 * aErrOrderFprev) + (0.1 * aErrOrder);
  aErrOrderFprev = aErrOrderF;

  float aPterm = aKp * aError;
  aPterm = constrain(aPterm, -255, 255);
  
  float aIterm = aKi * aErrSum;
  float aDterm = aKd * aErrOrderF;

  float controlAngle1 = aPterm + aIterm + aDterm;
  controlAngle1 = constrain(controlAngle1, -255, 255);

  aLastErr = aError;
  aLastTime = aCurrentTime;
  
  #ifdef DEBUG_ANGLE_PID
  Serial.print("aIterm:"); Serial.print(aIterm); Serial.print(",");
  Serial.print("sIterm:"); Serial.print(sIterm); Serial.print(",");
  Serial.print("sDterm:"); Serial.println(sDterm);
  #endif

  return controlAngle1;
}

void gyro_signals(void) {
  Wire.beginTransmission(0x68);
  Wire.write(0x1A);
  Wire.write(0x05);
  Wire.endTransmission();
  Wire.beginTransmission(0x68);
  Wire.write(0x1C);
  Wire.write(0x10);
  Wire.endTransmission();
  Wire.beginTransmission(0x68);
  Wire.write(0x3B);
  Wire.endTransmission(); 
  Wire.requestFrom(0x68,6);
  int16_t AccXLSB = Wire.read() << 8 | Wire.read();
  int16_t AccYLSB = Wire.read() << 8 | Wire.read();
  int16_t AccZLSB = Wire.read() << 8 | Wire.read();
  Wire.beginTransmission(0x68);
  Wire.write(0x1B); 
  Wire.write(0x8);
  Wire.endTransmission();     
  Wire.beginTransmission(0x68);
  Wire.write(0x43);
  Wire.endTransmission();
  Wire.requestFrom(0x68,6);
  int16_t GyroX=Wire.read()<<8 | Wire.read();
  int16_t GyroY=Wire.read()<<8 | Wire.read();
  int16_t GyroZ=Wire.read()<<8 | Wire.read();
  RateRoll=(float)GyroX/65.5;
  RatePitch=(float)GyroY/65.5;
  RateYaw=(float)GyroZ/-65.5;
  AccX=(float)AccXLSB/4096-0.01;
  AccY=(float)AccYLSB/4096+0.01;
  AccZ=(float)AccZLSB/4096+0.05;
  AngleRoll=atan(AccY/sqrt(AccX*AccX+AccZ*AccZ))*1/(3.142/180);
  AnglePitch=-atan(AccX/sqrt(AccY*AccY+AccZ*AccZ))*1/(3.142/180);
  AngleYaw=atan2(AccY, AccX)*1/(3.142/180);
}

encoderData getEncoderData(){
  unsigned long currentMillis = millis();
  unsigned long time = (currentMillis - lastMillis);

  if (time > 10){
    long count = (counter - lastCounter);

    bool encDIR;

    float seconds = (time/1000.0);

    float revolutions = count/200.0;

    float rps = revolutions/seconds;

    if (counter > lastCounter){
      encDIR = 1;
    } else{
      encDIR = -1;
    }
    
    lastMillis = currentMillis;
    lastCounter = counter;

    encoderData result;
    result.rpm = rps * encDIR;
    result.direction = encDIR;

    #ifdef DEBUG_ENCODER
    Serial.print("rps:");  Serial.print(rps, 3); Serial.print(",");
    Serial.print("counter:");  Serial.println(counter);
    #endif

    return result;
  }
}

void pidInit(){
  // Read float values from EEPROM
  EEPROM.get(0, sKp); // Read sKp (float) from EEPROM starting at address 0
  EEPROM.get(4, sKi); // Read sKi (float) from EEPROM starting at address 4
  EEPROM.get(8, sKd); // Read sKd (float) from EEPROM starting at address 8
  EEPROM.get(12, aKp); // Read aKp (float) from EEPROM starting at address 12
  EEPROM.get(16, aKi); // Read aKi (float) from EEPROM starting at address 16
  EEPROM.get(20, aKd); // Read aKd (float) from EEPROM starting at address 20
  
  Serial.print("sKp = "); Serial.print(sKp, 3); Serial.print(" , "); 
  Serial.print("sKi = "); Serial.print(sKi); Serial.print(" , "); 
  Serial.print("sKd = "); Serial.print(sKd); Serial.print(" , "); 
  Serial.print("aKp = "); Serial.print(aKp, 3); Serial.print(" , "); 
  Serial.print("aKi = "); Serial.print(aKi); Serial.print(" , "); 
  Serial.print("aKd = "); Serial.println(aKd, 3);
}

void mpuInit(){
  pinMode(13, OUTPUT);
  digitalWrite(13, HIGH);
  Wire.setClock(400000);
  Wire.begin();
  delay(250);
  Wire.beginTransmission(0x68); 
  Wire.write(0x6B);
  Wire.write(0x00);
  Wire.endTransmission();
  for (RateCalibrationNumber=0; RateCalibrationNumber<2000; RateCalibrationNumber ++) {
    gyro_signals();
    RateCalibrationRoll+=RateRoll;
    RateCalibrationPitch+=RatePitch;
    RateCalibrationYaw+=RateYaw;
    delay(2);
  }
  RateCalibrationRoll/=2000;
  RateCalibrationPitch/=2000;
  RateCalibrationYaw/=2000;

  LoopTimer=micros();
}

void encoderInit(){
  pinMode(2, INPUT_PULLUP); // Internal pull-up for pin 2
  pinMode(3, INPUT_PULLUP); // Internal pull-up for pin 3

  attachInterrupt(digitalPinToInterrupt(2), ai0, RISING);  // Interrupt on pin 2 (encoder A)
  attachInterrupt(digitalPinToInterrupt(3), ai1, RISING);  // Interrupt on pin 3 (encoder B)

  Serial.println("Encoder connection successful");
}

void motorInit(){
  InitTimersSafe();
  SetPinFrequencySafe(motorPWM_Pin, Nidec_Frequency);

  pinMode(motorPWM_Pin, OUTPUT);
  pinMode(motorDIR_Pin, OUTPUT);
  pinMode(motorBrake_Pin, OUTPUT);

  pwmWrite(motorPWM_Pin, 255);
  digitalWrite(motorDIR_Pin, HIGH);
  digitalWrite(motorBrake_Pin, LOW);

  motorDIR = 1;
  Serial.println("Motor connection successful");
}

void tunePID(){
  char cmd = Serial.read();

  switch (cmd){
    case 'q': sKp += 0.001; EEPROM.put(0, sKp);
    break;
    
    case 'a': sKp -= 0.001; EEPROM.put(0, sKp);
    break;
    
    case 'w': sKi += 0.01; EEPROM.put(4, sKi);
    break;
  
    case 's': sKi -= 0.01; EEPROM.put(4, sKi);
    break;
    
    case 'e': sKd += 0.01; EEPROM.put(8, sKd);
    break;
    
    case 'd': sKd -= 0.01; EEPROM.put(8, sKd);
    break;
    
    case 'r': aKp += 0.01; EEPROM.put(12, aKp);
    break;
    
    case 'f': aKp -= 0.01; EEPROM.put(12, aKp);
    break;
    
    case 't': aKi += 0.01; EEPROM.put(16, aKi);
    break;
    
    case 'g': aKi -= 0.01; EEPROM.put(16, aKi);
    break;
    
    case 'y': aKd += 0.001; EEPROM.put(20, aKd);
    break;
    
    case 'h': aKd -= 0.001; EEPROM.put(20, aKd);
    break;

    case 'z': 
      sKp = 0; sKi = 0; sKd = 0; aKp = 0; aKi = 0; aKd = 0;
      for (int i = 0; i < 25; i++){
        EEPROM.write(i, 0);
      }
    break;
 
    case 'x': 
      sKp = 0.276; sKi = 0.02; sKd = 0; aKp = 2.470; aKi = 0; aKd = 0.200;
      EEPROM.put(0, sKp); EEPROM.put(4, sKi); EEPROM.put(8, sKd); EEPROM.put(12, aKp); EEPROM.put(16, aKi); EEPROM.put(20, aKd);
    break;

    case 'c': 
      sKp = 0.375; sKi = 0.02; sKd = 0; aKp = 2.070; aKi = 0.01; aKd = 0.300;
      EEPROM.put(0, sKp); EEPROM.put(4, sKi); EEPROM.put(8, sKd); EEPROM.put(12, aKp); EEPROM.put(16, aKi); EEPROM.put(20, aKd);
    break;

    case 'l': run = !run;
    break;
    
    case 'p': stream = !stream;
    break;
    
    default: Serial.println("<Error - no tuning value>");
    cmd = Serial.read();    
  }

  if (stream == false){
    Serial.print("sKp = "); Serial.print(sKp, 3); Serial.print(" , "); 
    Serial.print("sKi = "); Serial.print(sKi); Serial.print(" , "); 
    Serial.print("sKd = "); Serial.print(sKd); Serial.print(" , "); 
    Serial.print("aKp = "); Serial.print(aKp, 3); Serial.print(" , "); 
    Serial.print("aKi = "); Serial.print(aKi); Serial.print(" , "); 
    Serial.print("aKd = "); Serial.println(aKd, 3);
  }
}
